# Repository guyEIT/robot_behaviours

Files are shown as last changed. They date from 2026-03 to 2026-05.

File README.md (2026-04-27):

# Robot Skills Framework — ROS 2 Jazzy

A discovery-based robot/instrument orchestration framework. Every skill — hardware-bound (MoveIt2 arm motion, pylabrobot instrument calls) or software-only (LLM-authored scripts) — is exposed as a self-advertising **ROS 2 action**. The orchestrator never hardcodes endpoints; it subscribes to latched `<node>/skills` manifests and dispatches goals over DDS.

Built on **ROS 2 Jazzy** + **MoveIt2** + a Python BehaviorTree.CPP-v4-compatible executor.

## Architecture

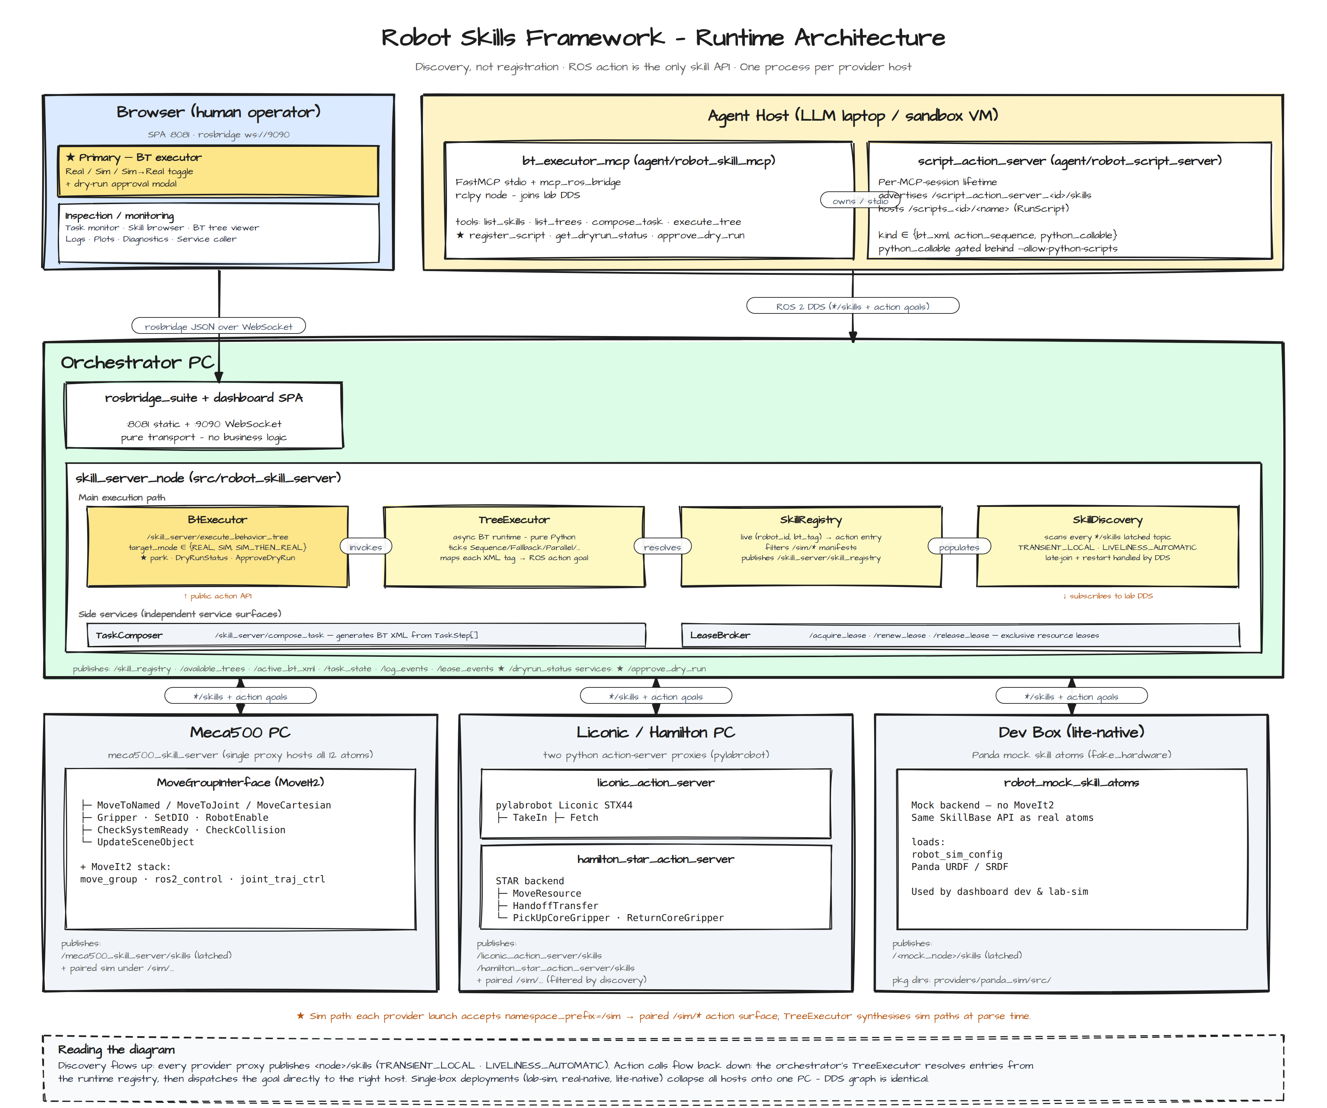
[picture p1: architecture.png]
Architecture diagram


Vector version: [architecture.svg](architecture.svg). Full text writeup: [architecture.md](architecture.md). Editable source: [architecture.excalidraw](architecture.excalidraw) (open at [excalidraw.com](https://excalidraw.com)).

**Core principles**

1. **A ROS action is the only skill API.** C++/MoveIt arm skills, Python/pylabrobot instrument skills, and agent-authored scripts all advertise the same way and are dispatched the same way.
2. **Discovery, not registration.** Every node hosting skills publishes a latched `<node>/skills` manifest with `TRANSIENT_LOCAL` durability and `LIVELINESS_AUTOMATIC` QoS. Restart and late-join are handled by DDS, not heartbeats.
3. **Topology = trust.** Code runs on the host that owns its execution context. The orchestrator never executes agent-authored code; it dispatches to ROS endpoints.
4. **One process per provider host.** Each robot/instrument PC runs a single skill-server-proxy node hosting all of that host's actions.
5. **Each top-level directory maps to one deployment role.**

## Directory layout

| Top-level dir | Role | Runs on |
|---|---|---|
| [lib/](lib/) | Shared libraries — host-agnostic, no runtime | Consumed by every host |
| [src/](src/) | Orchestrator processes + assets | Orchestrator PC |
| [agent/](agent/) | MCP-host processes + agent-local services | Agent's machine (anywhere on DDS) |
| [providers/](providers/) | Per-robot/instrument code | The robot/instrument PC |

### Providers

| Provider | Code | Skills |
|---|---|---|
| Mecademic Meca500 6-DoF arm | [providers/meca500/](providers/meca500/) | 12 MoveIt2 atoms (MoveToNamed/Joint/Cartesian, Gripper, SetDIO, RobotEnable, CheckSystemReady, CheckCollision, UpdateSceneObject, …) |
| Generic Panda 7-DoF (mock backend) | [providers/panda_sim/](providers/panda_sim/) | robot-agnostic mock skill atoms used by `lab-sim` and `lite-native`. The mocks no longer hardcode a robot — `lite-native` displays the Meca500 model in the dashboard while reusing the lightweight Python mocks; the panda URDF stays available for callers that override `joint_names` / `initial_positions` / `arm_joint_count` on the launch CLI. |
| PBI Liconic STX44 incubator | [providers/pbi_liconic/](providers/pbi_liconic/) | TakeIn, Fetch (pylabrobot) |
| Hamilton STAR liquid handler | [providers/pbi_liconic/](providers/pbi_liconic/) | MoveResource, HandoffTransfer, PickUpCoreGripper, ReturnCoreGripper |
| Imaging station (sim) | [providers/imaging_station/](providers/imaging_station/) | ImagePlate — currently a sim that writes placeholder PNGs; real driver swaps in via the same action |

Both Liconic and Hamilton are pulled from the `guyEIT/pbi_liconic` upstream as a `git subtree`. See [CLAUDE.md](CLAUDE.md) for the subtree pull/push commands.

The imaging-station provider is a fresh in-tree provider, not a subtree — it owns the `robot_skills_msgs/action/ImagePlate` interface and ships a sim backend so the campaign behaviour tree can run a full Liconic ↔ Hamilton ↔ Imager ↔ Hamilton ↔ Liconic loop without imager hardware. Real driver backends (BMG / Tecan / BioTek / microscope) plug into the same action interface.

## Quick start

### Prerequisites

- Pixi (Linux desktop). Docker Compose remains as a fallback path.
- A populated local conda channel at `~/channel` hosting `ros-jazzy-robot-skills-msgs` (one-time bootstrap).

### One-time bootstrap

```bash
bash scripts/bootstrap-msgs.sh
```

Builds `robot_skills_msgs` into `~/channel/`. Required because pixi 0.67 eagerly resolves all envs and the native envs reference `~/channel`.

### Run the whole lab in sim (single command)

```bash
pixi run lab-sim-up
# open http://localhost:8081 — pick test_meca500_sim / test_hamilton_sim / test_liconic_smoke
```

Brings up *every* provider sim + skill atoms + skill_server + dashboard in one `ros2 launch`. Validated end-to-end (hamilton 0.54 s, liconic 0.54 s, meca500 8.80 s).

### Per-provider sim (one provider in isolation)

```bash
pixi run meca500-sim-test    # MoveIt fake_hardware + Meca atoms + skill_server
pixi run hamilton-sim-test   # STAR sim backend + skill_server
pixi run liconic-sim-test    # Liconic sim backend + skill_server
```

Submit the matching test tree from [src/robot_behaviors/trees/](src/robot_behaviors/trees/).

### Single-box deployments

| Mode | Command | What runs |
|---|---|---|
| `lite-native` | `pixi run lite-native-up` | dashboard + orchestration with mock atoms (no MoveIt2) |
| `real-native` | `pixi run real-native-up` | full real-robot stack on one PC |
| `lab-sim` | `pixi run lab-sim-up` | every provider sim + dashboard |
| ★ `lab-up` | `pixi run lab-up` | `lab-sim` + paired `/sim/*` instances for `MODE_SIM_THEN_REAL` testing |

### Distributed production

Per-PC pixi envs install only what each box needs. All share `ros-jazzy-robot-skills-msgs` from `~/channel`.

| Env | Target PC | Tasks |
|---|---|---|
| `orchestrator` | control PC | `orchestrator-up` |
| `meca500-host` | Meca500 robot PC | `meca500-moveit-run` + `meca500-atoms-run`; `meca500-sim-up` for fake_hardware |
| `liconic-host` | Liconic / Hamilton PC | `liconic-up`, `liconic-sim-up`, `hamilton-up`, `hamilton-sim-up` |
| `lite-native` | dev box | `lite-native-up` |
| `real-native` | single-box real robot | `real-native-up` |

### Common workflows

```bash
# Rebuild only msgs after editing a .msg/.srv/.action
pixi run update-msgs

# Open a sourced ROS shell
pixi run lite-native-shell        # or real-native-shell, meca500-host shell, etc.

# Inspect the running ROS graph
pixi run status

# Run the test suite
pixi run test
```

## Calling skills

```bash
# List the skill registry (merged view of every */skills topic)
ros2 service call /skill_server/get_skill_descriptions \
  robot_skills_msgs/srv/GetSkillDescriptions \
  '{include_compounds: true, include_pddl: false}'

# Execute a behavior tree XML
ros2 action send_goal /skill_server/execute_behavior_tree \
  robot_skills_msgs/action/ExecuteBehaviorTree \
  "$(python3 -c 'import yaml,sys; xml=open(sys.argv[1]).read(); print(yaml.safe_dump({"tree_xml": xml, "tree_name": "demo", "target_mode": 0}, default_style="|"))' src/robot_behaviors/trees/move_to_home.xml)"

# Compose a tree from skill steps
ros2 service call /skill_server/compose_task \
  robot_skills_msgs/srv/ComposeTask \
  '{
    task_name: "my_task",
    sequential: true,
    steps: [
      {skill_name: "move_to_named_config", parameters_json: "{\"config_name\": \"home\"}"},
      {skill_name: "gripper_control",       parameters_json: "{\"command\": \"open\"}"}
    ]
  }'

# Sanity-check a plan against PDDL preconditions / effects before running it
ros2 service call /skill_server/validate_plan \
  robot_skills_msgs/srv/ValidatePlan \
  '{
    initial_state: ["robot_initialized", "gripper_open"],
    steps: [
      {skill_name: "move_to_named_config", parameters_json: "{\"config_name\": \"home\"}"},
      {skill_name: "pick_object",           parameters_json: "{}"}
    ]
  }'
# Returns valid=true + final_state, OR valid=false + first_failing_step
# + missing_preconditions[] pointing at the offending entry.
```

`target_mode` on `ExecuteBehaviorTree`: `0 = MODE_REAL` (default, back-compat), `1 = MODE_SIM` (one-shot dry-run), `2 = MODE_SIM_THEN_REAL` (sim → operator approval gate → real).

## Sim-before-real workflow ★

Long-running plans (multi-step assays, hours-long incubations) get a fast pre-flight against a paired `/sim/*` action surface, then a human approval gate before the real phase runs.

- Each provider launch accepts `namespace_prefix:=/sim` and wraps its action servers in a `PushRosNamespace` group.
- `SkillDiscovery` filters out `/sim/*` manifests so the registry is single-source-of-truth on real entries.
- `TreeExecutor` synthesises the sim path at parse time by string-prepending `/sim` — same XML, both phases.
- On a successful sim phase, `BtExecutor` latches a `DryRunStatus` on `/skill_server/dryrun_status` and waits on `/skill_server/approve_dry_run` (`ApproveDryRun.srv`). The dashboard surfaces an approve/reject modal.

## Long-lived campaign workflow ★

For trees that run for **weeks** — operators trickling plates in and out of the Liconic, cycling each through the Hamilton-iSWAP to the imaging station and back — the framework persists tree state to SQLite and resumes after a `skill_server` crash without losing progress.

**What survives a restart:**

- A SQLite-backed *persistent blackboard*: any key prefixed `persistent.` is mirrored to `~/.local/state/skill_server/tasks/{task_id}/state.db` (WAL mode). Type-checked at write — only JSON-serialisable values land on disk.
- *Per-node tick checkpoints* on every control / decorator / loop node (`Sequence` index, `Repeat` iteration, `RetryUntilSuccessful` attempt, `WaitUntil` deadline). On resume, the executor re-ticks from the root and each Checkpointable node hydrates its index — no work is repeated past the last successful child.
- *Action-inflight reconciliation*: every `RosActionNode` records `(node_path, server_name, goal_uuid, idempotent)` before submitting. If a goal was in flight at crash time, the resume path inspects the row — idempotent skills auto-resubmit; non-idempotent skills refuse and surface an alert for the operator to resolve via `OperatorDecision`.

**New control / utility nodes** in `tree_executor.py`:

- `KeepRunningUntilFailure`, `Repeat num_cycles="N"`, `WhileDoElse`
- `WaitUntil timestamp="{...}"` — wall-clock-aware sleep (deadline-preserving across restart)
- `BlackboardCondition key="..." expected="..."` — gate a subtree on a persistent flag
- `PopFromQueue` / `PushToQueue` — list-valued blackboard queues for operator-driven work
- `AdvancePlate` — post-cycle bookkeeping (increments cycle, recomputes `next_due_at`, retires when target reached)

**Operator services** — split between `bb_operator` (campaign-level state) and `skill_server` (framework-level execution control):

| Service | Owner | Purpose |
|---|---|---|
| `/bb_operator/add_plate` | sidecar | append a plate dict to `persistent.plate_queue` (trickle-in) |
| `/bb_operator/retire_plate` | sidecar | flag `plates.{name}.retiring = true` so the in-flight cycle finishes naturally and isn't re-queued |
| `/bb_operator/pause_campaign` | sidecar | toggle `persistent.paused`; `BlackboardCondition` gate halts the next iteration boundary |
| `/bb_operator/operator_decision` | sidecar | resolve a stuck non-idempotent action (`retry` / `skip-as-success` / `skip-as-failure` / `abort-tree`) |
| `/skill_server/pause_execution` | bt_executor | framework-level pause that sets `ctx.paused`, honoured at step boundaries by every control-flow node — works for any tree, not just campaigns |
| `/skill_server/cancel_active_task` | bt_executor | session-independent hard cancel; walks `_current_ctx`, sets `cancelled`, and tears down in-flight goals — reachable by *any* client (the action-cancel handshake requires the original goal id, which a restarted dashboard doesn't have) |

**Live dashboard view.** The dashboard's **Campaign** panel (added 2026-04-27) subscribes to `/skill_server/persistent_state` — a latched JSON snapshot of the active task's persistent blackboard, republished by `bb_operator` after every service handler + a 1 Hz timer. Renders the plate queue + per-name index as a table with cycle / cadence / next-due / status; surfaces **Add Plate** (modal dialog), **Pause after step** / **Resume**, **Cancel** (hard halt via `/skill_server/cancel_active_task`), and per-row **Retire** trash icons. The `Campaign` preset layout (Layouts → CAMPAIGN) tiles it alongside Task Monitor + BT Tree + Executor + Logs. Validated end-to-end via Playwright + chromium-headless: empty-state → submit campaign tree → AddPlate → Pause → Resume → Cancel.

**The campaign tree** lives at [src/robot_behaviors/trees/campaign/plate_imaging_campaign.xml](src/robot_behaviors/trees/campaign/plate_imaging_campaign.xml). Outer loop is `KeepRunningUntilFailure → BlackboardCondition(paused == false) → Sequence(Pop → WaitUntil → SubTree → AdvancePlate)`. Inner `PlateImageCycle` subtree wraps the iSWAP transfers, ImagePlate, and Liconic round-trip in a `RetryUntilSuccessful num_attempts=2`.

**Skill idempotency** is declared per atom in `SkillDescription.idempotent` (defaults to `false`). The resume path uses it to decide whether to auto-resubmit on goal-gone or to halt and ask the operator.

## MCP / agent surface

Agents (LLMs, MCP clients) drive the lab through [agent/robot_skill_mcp/](agent/robot_skill_mcp/) — a FastMCP stdio server bridged into ROS:

| Tool | Purpose |
|---|---|
| `list_skills`, `list_trees` | introspect the runtime registry |
| `compose_task` | build a BT XML from steps |
| `execute_tree` | dispatch `/skill_server/execute_behavior_tree` |
| `register_script`, `list_scripts`, `delete_script` | session-scoped agent-authored skills |
| `get_dryrun_status`, `approve_dry_run` | drive the sim-then-real gate |

Agent-authored scripts run on the agent's host via [agent/robot_script_server/](agent/robot_script_server/) — the orchestrator never executes agent code; from its point of view a registered script is just another `RunScript`-typed action.

## Live update

`./src` is bind-mounted into the dev container; `colcon build --symlink-install` symlinks Python and XML share files back to source.

| Change type | Action |
|---|---|
| Behavior tree XML | save the file — `BtExecutor` polls every 2 s, dashboard updates over the latched topic |
| Python orchestrator code | save the file — symlinked. Restart the node only if it caches state at startup |
| C++ atoms | `colcon build --packages-select <pkg>` + node restart |
| Frontend | `vite build` + `colcon build --symlink-install --packages-select robot_dashboard` (or `pixi run dashboard-dev` for hot reload) |

## Adding a skill

See [docs/adding-skills.md](docs/adding-skills.md) and the Claude Code commands:

- `/new-skill-atom` — generic primitive (lib/robot_arm_skills) or provider-specific atom
- `/new-compound-skill` — vetted, persisted compound skill
- `/new-behavior-tree` — XML tree
- `/debug-skill` — diagnose a failing skill or tree

## Docker fallback

Local Pixi is the preferred path; Docker remains as a fallback.

```bash
pixi run lite-up   pixi run lite-logs    pixi run lite-down
pixi run real-up   pixi run real-logs    pixi run real-down
pixi run docker-status
```

| Container | Image | Purpose |
|---|---|---|
| `ros2_robot_skills_lite` | `ros2-jazzy-robot-skills-lite` | lite mock skill stack |
| `ros2_robot_skills_dev` | `ros2-jazzy-robot-skills` | real robot skill server |

Containers use host networking for DDS discovery and bind-mount `./src`.

## Further reading

- [architecture.md](architecture.md) — full architecture writeup
- [CLAUDE.md](CLAUDE.md) — development environment, validation status, known follow-ups
- [docs/adding-skills.md](docs/adding-skills.md)

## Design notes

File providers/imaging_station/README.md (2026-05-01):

# imaging_station provider

Generic plate imaging-station provider for the Robot Skills Framework. Owns
the `robot_skills_msgs/action/ImagePlate` action; ships a sim backend that
writes placeholder PNGs and a live NDI receiver node that republishes a
remote NDI source (e.g. ZowieBox-40435) as `sensor_msgs/Image`.

## Packages

- **`imaging_station`** (ament_python) — the action server + bridge node.
  - `imaging_station_sim_node` — placeholder PNG sim, serves `ImagePlate`.
  - `imaging_station_ndi_node` — spawns the C++ NDI bridge, publishes frames.
- **`imaging_station_ndi_bridge`** (ament_cmake) — the native `ndi_av_bridge`
  binary. Vendored verbatim from the experiment_collector workspace.

## Sim backend

```
ros2 launch imaging_station imaging_station_sim.launch.py
```

Writes one PNG per requested site under
`~/.local/state/imaging_station/{plate_name}/{epoch_ms}_{counter}/site_{i}.png`.
No hardware required.

## NDI bridge node (live ZowieBox / any NDI source)

Connects to a named NDI source and publishes BGR8 `sensor_msgs/Image` frames
on `/imaging_station/image_raw`.

```
ros2 launch imaging_station imaging_station_ndi.launch.py \
  ndi_source_name:="ZOWIEBOX-40435 (ZowieBox-40435)"
ros2 run rqt_image_view rqt_image_view /imaging_station/image_raw
```

### Prerequisites — NDI 6 SDK

The bridge `dlopen`s `libndi.so.6` at runtime; the build needs
`Processing.NDI.Lib.h` at compile time. Neither is on conda-forge (NDI is
license-gated by Vizrt), so you must install it once per pixi env:

1. Download `Install_NDI_SDK_v6_Linux.tar.gz` from
   <https://ndi.video/for-developers/ndi-sdk/download/>.
2. Drop it at `vendor/ndi/Install_NDI_SDK_v6_Linux.tar.gz`.
3. Run `pixi run setup-ndi` (or `bash scripts/setup-ndi-host.sh` directly —
   the script does not require an active pixi env).
4. Run `pixi run lite-native-install` so the bridge package picks up the
   newly-installed headers and produces the `ndi_av_bridge` binary.

The script ([scripts/setup-ndi-host.sh](../../scripts/setup-ndi-host.sh))
extracts the tarball, runs the Vizrt installer non-interactively, and copies
headers + `libndi.so.6` into `$HOME/.ndi-sdk/{include,lib}/`. That host-stable
per-user prefix is reachable both by the pixi-build-ros build sandbox (via
`FindNDISdk.cmake`) and by the runtime (the bridge dlopens `libndi.so.6`
through `IMAGING_STATION_NDI_RUNTIME_DIR`, which the `lite-native` activation
env points at the same dir).

If you skip step 3, `pixi install -e lite-native` still succeeds — the bridge
build prints a `STATUS` warning and the package installs without the
executable, so unrelated lite-native development isn't blocked.

### Discovery on multi-NIC hosts

libndi's built-in mDNS implementation can silently fail on hosts with multiple
network interfaces (Linux multicast picks one route, which may not be the one
the source advertises on). The node falls back to `avahi-browse` automatically
to resolve `host:port`, then passes that to the bridge as `--url-address` so
the bridge connects directly without going through libndi's mDNS at all.

If discovery still fails, force it with the `url_address` parameter:

```
ros2 launch imaging_station imaging_station_ndi.launch.py \
  url_address:=10.6.105.98:5961
```

### "Video decoder not found"

NDI 6.3.x dlopens `libavcodec.so.61` / `libavutil.so.59` (FFmpeg 7.x SONAMEs)
and a cluster of codec helpers (`dav1d`, `openjp2`, `speex`, `lcms2`, `libva`).
Ubuntu's system FFmpeg is too old (60/58); conda-forge has the right versions
but only when explicitly pulled in.

The fix is wired through pixi: `[feature.lite-native.dependencies]` declares
`gst-libav` (transitively pulls FFmpeg 7.x), plus `lcms2 / dav1d / openjpeg /
speex / avahi`. `pixi run setup-ndi` then assembles
`$PROJECT_ROOT/.ndi-runtime-bundle/lib/` by copying `libndi.so.6` from
`$HOME/.ndi-sdk/` and the FFmpeg + codec libs from `$CONDA_PREFIX/lib`,
creating the SONAME aliases NDI looks for (`libavcodec-ndi.so.61` →
`libavcodec.so.61.X.Y.Z` etc.). The bundle path is exported as
`IMAGING_STATION_NDI_RUNTIME_DIR` by the `lite-native` activation env.

If you bump conda-forge versions later (e.g. FFmpeg 8.x lands), rebuild the
bundle to refresh the symlinks:

```
pixi run setup-ndi-bundle
```

### Network

NDI uses mDNS for source discovery; the imager and the host running the node
must be on the same broadcast domain (or use NDI Discovery Server / explicit
`url_address` overrides). Confirm your ZowieBox is visible:

```
ros2 run imaging_station_ndi_bridge ndi_av_bridge --help    # bridge CLI
```

…and look for the source name in `imaging_station_ndi_node`'s startup log
("Visible NDI sources (N): [...]").

### Parameters

| name | default | meaning |
|---|---|---|
| `ndi_source_name` | `"ZOWIEBOX-40435 (ZowieBox-40435)"` | NDI source to subscribe to |
| `frame_id` | `imaging_station_camera_optical_frame` | `frame_id` stamped on every Image |
| `target_fps` | `0.0` | Cap publish rate (0 = pass through) |
| `discovery_timeout_sec` | `5.0` | mDNS discovery wait at startup |
| `bandwidth` | `highest` | NDI receiver bandwidth (`highest`/`lowest`)  |
| `image_topic` | `image_raw` | Topic name (under `/imaging_station/`) |
| `camera_info_topic` | `camera_info` | CameraInfo topic name (under `/imaging_station/`) |
| `camera_info_url` | `<share>/imaging_station/calibration/zowiebox_camera_info.yaml` | Calibration YAML; empty/missing → 50° HFOV placeholder |
| `startup_timeout_sec` | `12.0` | Bridge waits this long for the source |

The node publishes a `sensor_msgs/CameraInfo` paired 1:1 with each Image
(matching `header.stamp` + `frame_id`, both `BEST_EFFORT` QoS). When
`camera_info_url` points at a present file the standard
`camera_calibration_parsers` YAML is loaded; otherwise the node
synthesises a 50° HFOV pinhole `CameraInfo` from the live frame
dimensions — good for RViz frustum visualisation, **not** for metric
reconstruction. Replace
[calibration/zowiebox_camera_info.yaml](src/imaging_station/calibration/zowiebox_camera_info.yaml)
with real `camera_calibration` output once a checkerboard pass has been
done at the macro lens's nominal working distance.

The static TF `microscope_camera → imaging_station_camera_optical_frame`
(0.193 m along +Z, 180° roll so Z-forward points down through the lens —
ROS optical-frame convention X-right Y-down Z-forward; override
translation with `optical_offset_z:=…` and rotation with
`optical_roll:=…` / `optical_pitch:=…` / `optical_yaw:=…`) is
published by
[imaging_station_scene.launch.py](launch/imaging_station_scene.launch.py),
which `meca500_bringup/moveit.launch.py` already includes via
`show_imaging_station:=true`. Run `pixi run meca500-real-up` (or the sim
equivalent) and the optical frame appears in RViz relative to
`meca_base_link` without the bridge running.

## Follow-ups

- A real `ImagePlate` backend that captures N frames per site from the live
  NDI stream and writes them to `output_root` (replacing or living alongside
  `sim_backend`). Today the sim and the NDI bridge run independently.
- Audio packets from the bridge are dropped in v1; add a ROS publisher when
  a consumer materialises.
- Replace the placeholder
  [zowiebox_camera_info.yaml](src/imaging_station/calibration/zowiebox_camera_info.yaml)
  with real intrinsics from `camera_calibration` once the macro lens has
  been calibrated against a checkerboard at its nominal working distance.

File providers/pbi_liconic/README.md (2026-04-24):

# plr — pylabrobot + ROS 2 for a Hamilton STAR

Scripts and a ROS 2 action server for driving a Hamilton STAR (8-channel)
through [pylabrobot](https://github.com/PyLabRobot/pylabrobot), including
off-deck plate handoffs to external instruments (incubator, cytomat, etc.)
via the STAR's firmware "hotel" commands.

Everything runs inside [`pixi`](https://pixi.sh) environments so the
underlying conda + ROS 2 Humble (RoboStack) stack stays reproducible.

## Quick start

```bash
pixi install -e ros2             # builds the three ROS 2 packages as
                                 # conda packages via pixi-build-ros

# One shell — run the action server against real hardware
pixi run -e ros2 action-server

# Another shell — drive it
pixi run -e ros2 ros2-move-to-incubator -- --yes
```

To run without hardware (STAR chatterbox simulator):

```bash
pixi run -e ros2 action-server-sim
```

Editing a source file? Just rerun `pixi run -e ros2 <task>` — pixi-build
sees the change and rebuilds the affected package automatically. No
`colcon build`, no `source install/setup.bash`.

## Repo layout

```
scripts/       Direct-hardware scripts + ROS 2 client scripts + the
               teach pendant. Each one is runnable via a pixi task.
ros2_ws/       The ROS 2 workspace. Five packages:
  hamilton_star_msgs/    STAR action/msg/srv definitions
  hamilton_star_ros/     STAR action server implementation
  hamilton_star_bringup/ STAR launch files + default deck + handoff config
  liconic_msgs/          STX incubator action/msg/srv definitions
  liconic_ros/           STX action server + launch file + plate registry
```

## Two worlds

The repo has two sets of tools depending on how much infrastructure you
want in the way:

- **Direct scripts** (`scripts/`, default pixi env) — open their own USB
  connection to the STAR, do one thing, disconnect. Useful for bring-up,
  recovery, and teaching calibrations. Examples: `pixi run test-iswap`,
  `pixi run iswap-teach`, `pixi run iswap-release`.
- **ROS 2 action server** (`ros2_ws/`, `ros2` pixi env) — persistent
  process, one USB connection, async actions + services. This is what
  bigger workflows should target. Launched via
  `pixi run -e ros2 action-server`; client scripts in `scripts/` with a
  `test_ros2_*.py` prefix hit it via ROS 2 actions.

## ROS 2 architecture

```
hamilton_star_msgs/     action + msg + srv definitions
hamilton_star_ros/      the node implementation
  action_server.py      rclpy plumbing (one action per goal type)
  machine.py            async facade over pylabrobot.LiquidHandler
  machine_fsm.py        operational state + substate gating
  machine_lock.py       per-channel / per-resource RW lock
  iswap_handoff.py      6-stage manual-jog recipe for off-deck transfers
  handoff_registry.py   runtime CRUD for off-deck handoff sites
  asyncio_bridge.py     bridges rclpy's callback threads to one asyncio loop
hamilton_star_bringup/  launch files + deck/handoff config
```

### Actions & services

The server exposes roughly two flavours:

- **Pipetting / move**: `pick_up_tips`, `drop_tips`, `aspirate`, `dispense`,
  `transfer`, `aspirate96` etc., `move_resource`, `pick_up_core_gripper`,
  `return_core_gripper`, `jog_channel`.
- **iSWAP-specific**: `handoff_transfer` (6-stage manual-jog, diagnostic
  per-stage feedback — useful when the firmware atomic paths misbehave).

Plus services for lifecycle and configuration: `reset_error`,
`abort_motion`, `initialize_module`, `load_deck`, `serialize_deck`,
`list_resources`, `get_status`, `acknowledge_plate_released`,
`define_handoff`, `list_handoffs`, `delete_handoff`.

### Off-deck plate handoffs: the one-line story

```python
await move_resource(resource="six_well_01", to="incubator_handoff")
```

The server has a **handoff registry** (`handoff_registry.py`) of off-deck
sites — each entry holds the XYZ coordinate, the iSWAP grip parameters,
and the firmware hotel approach parameters (`hotel_depth`,
`hotel_clearance_height`). When you register a handoff via
`~/define_handoff`, the server also injects a matching `ResourceHolder`
onto the deck tree at that coordinate, so `MoveResource.to = <name>`
Just Works — you don't have to think about "is this on-deck or off-deck".
The server auto-detects that `to` names a registered handoff and routes
through pylabrobot's firmware-atomic `use_unsafe_hotel=True` path.

For tuning or diagnostic flows where you want step-by-step visibility,
`handoff_transfer` (6-stage manual jog) is still available.

### State machine

`machine_fsm.py` is the single authority over `op_state` (Disconnected /
Initializing / Idle / BusyShared / BusyExclusive / Aborting / Error) and
a bundle of orthogonal substate flags: per-channel tip/gripper state,
iSWAP init / y-path / holding-plate / drive-faulted / at-safe-pose, and
the last reached handoff stage (for post-mortem). Key recovery semantics:

- Any firmware exception during an iSWAP-driven action sets
  `iswap_drive_faulted = True`. Future goals that need the iSWAP are
  rejected at the FSM gate until cleared.
- `~/reset_error` does **soft** firmware recovery: re-init the iSWAP,
  verify it responds with a position query, *then* clear the FSM. If the
  firmware is still faulted, the service returns `success=False` with a
  hint to restart the server or power-cycle the STAR.
- `iswap_holding_plate` survives exceptions on purpose — the operator
  must physically inspect the gripper (optionally run `iswap-release`)
  and acknowledge via `~/acknowledge_plate_released`.

The [FSM self-healing plan](.claude/plans/what-can-we-do-prancy-river.md)
in the repo walks through the design.

## Pixi tasks

### Default env (direct, no ROS)

| Task | What it does |
|---|---|
| `pixi run test-star` | Minimal hardware ping |
| `pixi run test-sim` | Same against the chatterbox sim |
| `pixi run test-gripper` | CoRe II gripper pickup/return |
| `pixi run test-iswap` | iSWAP sanity test |
| `pixi run iswap-teach` | Launch the FastAPI teach pendant (port 8080) |
| `pixi run test-iswap-grab` | Pick up a 6-well plate (direct) |
| `pixi run iswap-release` | Recovery: release a stuck plate and park |
| `pixi run iswap-to-incubator` | Direct manual-jog transfer to the incubator |
| `pixi run iswap-from-incubator` | Same, reverse direction |

### `ros2` env (action server + clients)

| Task | What it does |
|---|---|
| `pixi install -e ros2` | Build & install the three ROS 2 packages as conda packages (pixi-build-ros). Re-runs automatically when source changes. |
| `pixi run -e ros2 action-server` | Launch the action server vs real hardware |
| `pixi run -e ros2 action-server-sim` | Same, against the chatterbox simulator |
| `pixi run -e ros2 test-ros2-sim` | `pytest` the hamilton_star_ros tests |
| `pixi run -e ros2 ros2-iswap-to-incubator` | HandoffTransfer (6-stage) client |
| `pixi run -e ros2 ros2-iswap-from-incubator` | HandoffTransfer, reverse |
| `pixi run -e ros2 ros2-move-to-incubator` | **Canonical** MoveResource-to-registered-handoff |
| `pixi run -e ros2 liconic-server` | Launch the Liconic STX action server (own process, own /dev/liconic_stx44, plate-registry JSON at `~/.local/state/liconic/plate_registry.json`) |
| `pixi run -e ros2 liconic-roundtrip` | Client: Liconic take-in + fetch (needs only the Liconic server running) |
| `pixi run -e ros2 liconic-workcell-roundtrip` | Client: full Hamilton → Liconic → Hamilton round-trip (needs BOTH action servers running) |

Pass extra args to any ROS 2 client with `--`:

```bash
pixi run -e ros2 ros2-move-to-incubator -- --yes --rails 15
```

## Handoff registry by example

```bash
# Look at what's already registered (seeded from handoffs.yaml on boot)
ros2 service call /hamilton_star_action_server/list_handoffs \
    hamilton_star_msgs/srv/ListHandoffs '{}'

# Register a new off-deck site
ros2 service call /hamilton_star_action_server/define_handoff \
    hamilton_star_msgs/srv/DefineHandoff '{
      handoff: {
        name: "cytomat",
        x: -216.0, y: 350.0, z: 120.0,
        plate_width: 80.0,
        rotation: "LEFT", wrist: "STRAIGHT", grip_direction: "FRONT",
        hotel_depth: 500.0,
        hotel_clearance_height: 8.0,
      },
      replace_existing: true
    }'

# Now move a plate there via the generic MoveResource action
ros2 action send_goal /hamilton_star_action_server/move_resource \
    hamilton_star_msgs/action/MoveResource \
    '{ resource: "six_well_01", to: "cytomat", transport: "iswap" }'
```

## Development

```bash
pixi run -e ros2 test-ros2-sim    # full sim-backed pytest
rm -rf .pixi/build && pixi install -e ros2   # force a clean rebuild
```

Pure-Python unit tests (FSM, locks, bridge, registry) don't need rclpy
and run in `~1 second`; the rclpy-backed tests spin up an in-process
action server with the chatterbox simulator.

### ROS 2 build

The three packages under `ros2_ws/src/` are built by
[pixi-build-ros](https://pixi.prefix.dev/latest/build/backends/pixi-build-ros/)
(preview feature in pixi). Each package has its own `pixi.toml`
declaring the backend, the ROS distro (`humble`), and any sibling
path-deps; the root `pixi.toml` references them via conda-style path
entries under `[feature.ros2.dependencies]`. Pixi resolves, builds,
and installs the packages into the `ros2` env as real conda packages,
so `import hamilton_star_msgs.action`, `ros2 launch hamilton_star_bringup
…`, and the pytest suite all work without a `source install/setup.bash`
step.

The legacy `ros2_ws/build/`, `ros2_ws/install/`, `ros2_ws/log/` dirs
from the old colcon setup can be deleted — they're not used.

## Hardware setup

Plug in the STAR's USB cable; install the udev rule once:

```bash
sudo ./install-udev.sh
```

See [README-hamilton-udev.md](README-hamilton-udev.md) for details.

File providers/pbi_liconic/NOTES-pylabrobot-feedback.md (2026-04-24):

# pylabrobot — iSWAP off-deck handoff, questions

We're trying to drive a plate from an on-deck carrier (rails=20) to an
off-deck incubator dock at X ≈ -219 mm on a Hamilton STAR via the atomic
path (`lh.move_resource(..., use_unsafe_hotel=True)`). The 6-stage manual
jog recipe works; the atomic one doesn't, and we suspect we're holding
something the wrong way round. Four questions where your guidance would
help.

---

## 1. Is there a way to address the iSWAP shoulder and wrist independently in the atomics?

Our teach-pendant calibration for the incubator dock is
`shoulder=LEFT, wrist=STRAIGHT`. We can reproduce it through the manual
helpers (`rotate_iswap_rotation_drive` + `rotate_iswap_wrist`) but we
can't find a way to express it through `GripDirection`:

- `GripDirection.LEFT` — plate ends up rotated 180° in the gripper
  (looks like shoulder LEFT but the wrist is offset from STRAIGHT).
- `GripDirection.RIGHT` — plate orientation correct, but the arm now
  extends the wrong way and can't reach a left-side dock.

None of the four `GripDirection` values produce the
`shoulder=LEFT, wrist=STRAIGHT` combo we need.

Is there an existing way to pass the two drives separately to the
atomics (`iswap_get_plate`, `unsafe.put_in_hotel`), or is the manual-jog
path the expected route for calibrations like this?

---

## 2. Is `use_unsafe_hotel` meant to be set per-side?

For an on-deck → off-deck transfer, only the drop side should run the
hotel firmware command — calling `get_from_hotel` (PO) on the on-deck
plate hits `R027 PositionNotReachable`. `LiquidHandler.move_resource`
forwards `**backend_kwargs` to both `pick_up_resource` and
`drop_resource`, so `use_unsafe_hotel=True` goes to both.

Is there a supported way to split kwargs per side that we've missed?
We've worked around it by calling `pick_up_resource` and `drop_resource`
separately, but it felt like going around the one-call `move_resource`
API.

---

## 3. What happens if `pickup_direction` differs from `drop_direction` on the atomic path?

If we pick up with `GripDirection.FRONT` and then
`put_in_hotel(grip_direction=LEFT)`, the firmware atomic fails with
`R027`. The PO/PI commands don't seem to rotate the wrist to match
`gr` during the approach; they plan as if the arm is already oriented.

Is there a layer we should be going through that inserts a wrist
rotation between pickup and drop when the directions differ, or is
matching them a hard caller requirement?

---

## 4. Post-init pose + first rotation crashes the wrist

After `initialize_iswap` (FI) the arm sits at Y ≈ 626 mm. Any atomic
that needs a shoulder rotation from that pose binds the wrist against
the back wall:

```
R002/82: Wrist twist drive movement error: drive locked or incremental sensor fault
```

`park_iswap` (PG) doesn't help — it also moves Y far back. We pre-park
manually with `move_iswap_y(330)` before any iSWAP atomic, which works,
but it feels like we're papering over something the atomic should
handle itself. Is manual pre-parking the intended pattern, or is there
a helper that does the right thing?

---

Happy to send diffs, teach files, or firmware traces for any of the
above if useful. The manual-jog path is fine as a fallback, but we'd
like to get `move_resource` working for handoffs where we can.

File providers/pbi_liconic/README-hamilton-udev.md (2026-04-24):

# Hamilton STAR USB setup

The STAR appears on USB as vendor `08af` (Hamilton Bonaduz AG). To let this
project talk to it without running as root, and to give the device a stable
name, install the included udev rule:

```bash
./install-udev.sh
```

What it does:

1. Copies [99-hamilton.rules](99-hamilton.rules) to
   `/etc/udev/rules.d/99-hamilton.rules`.
2. Reloads udev and re-triggers device events.
3. Adds your user to the `plugdev` group if it isn't already.

After running it:

- **Log out and back in** so the new group membership takes effect.
- **Replug the STAR's USB cable** (or power-cycle the robot) so the rule
  applies to the live device node.

## Verification

- `ls -l /dev/hamilton_star` — should be a symlink owned by group `plugdev`.
- `pixi run lsusb` — should list an `08af:` device.
- `pixi run test-star` — connects, prints machine configuration, exits.

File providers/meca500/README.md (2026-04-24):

# meca500_ros2
ROS 2 Controllers for the Mecademic Meca500 robot.

# Requirements
* [pixi](https://pixi.sh)
* ROS 2 Jazzy (provisioned automatically by pixi via RoboStack — no system install required)

# Installation
```bash
git clone git@github.com:guyEIT/meca500_ros2.git
cd meca500_ros2
pixi install
```

`pixi install` resolves every `package.xml` dependency against RoboStack and builds the four ROS packages via [pixi-build-ros](https://prefix-dev.github.io/pixi-build-backends/backends/pixi-build-ros/).

# Run Controller

```bash
pixi run launch-moveit
```

Other tasks (`pixi task list` for the full set):

* `pixi run launch-calibration` — startup calibration launch
* `pixi run moveit-setup` — MoveIt setup assistant
* `pixi run rviz` — rviz2
* `pixi run -e tools optimize-mecatable --help` — mesh optimizer (isolated env, no ROS deps)

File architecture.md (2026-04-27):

# Robot Skills Framework — Architecture

A ROS 2 Jazzy workspace that exposes every robot/instrument skill — hardware-bound or software-only — as a self-advertising ROS action. The orchestrator discovers skills at runtime by subscribing to latched `*/skills` topics; nothing is hardcoded. Behavior trees are authored as XML, composed from skill steps, and executed by a Python tree executor.

## Core principles

1. **A ROS action is the only skill API.** C++/MoveIt arm skills, Python/pylabrobot instrument skills, and agent-authored scripts all advertise the same way and are dispatched the same way.
2. **Discovery, not registration.** Every node hosting skills publishes a latched `<node>/skills` manifest with `TRANSIENT_LOCAL` durability and `LIVELINESS_AUTOMATIC` QoS. Restart and late-join are handled by DDS, not heartbeats.
3. **Topology = trust.** Code runs on the host that owns its execution context. The orchestrator never executes agent-authored code; it dispatches to ROS endpoints. An LLM-authored script lives on the agent's machine — DDS sees it as just another action server.
4. **One process per provider host.** Each robot/instrument PC runs a single skill-server-proxy node hosting all of that host's actions, not a fleet of one-skill-per-node executables.
5. **Each top-level directory maps to one deployment role.** A package's location tells you where it runs.

## Runtime graph

```
  EXTERNAL CLIENTS — neither lives on the orchestrator.

  ┌─────────────────────────────────────┐    ┌────────────────────────────────────────────────────┐
  │ Browser (human)                     │    │ AGENT HOST (LLM laptop / sandbox VM)               │
  │   loads SPA from :8081              │    │  ┌──────────────────────────────────────────────┐  │
  │   live ROS via ws://9090            │    │  │ Agent / LLM (Claude Code, custom MCP client) │  │
  │   (rosbridge)                       │    │  │   spawns bt_executor_mcp as stdio subprocess │  │
  │                                     │    │  └──────────────────┬───────────────────────────┘  │
  │   Surfaces: BT executor (with       │    │                     │ stdio                         │
  │     Real / Sim / Sim→Real toggle    │    │                     ▼                               │
  │     + dry-run approval modal),      │    │  ┌──────────────────────────────────────────────┐  │
  │     task monitor, skill browser,    │    │  │ bt_executor_mcp   (agent/robot_skill_mcp)    │  │
  │     BT tree viewer, logs, plots,    │    │  │   FastMCP stdio + mcp_ros_bridge             │  │
  │     diagnostics                     │    │  │   rclpy node — joins lab DDS                 │  │
  └────────────┬────────────────────────┘    │  │   tools: list_skills / list_trees /          │  │
               │ rosbridge JSON                │  │          compose_task / execute_tree /       │  │
               │ over WebSocket                │  │        ★ register_script /                   │  │
               │ ws://orchestrator:9090        │  │        ★ get_dryrun_status /                 │  │
               │                               │  │        ★ approve_dry_run                     │  │
               │                               │  └────────────────────┬─────────────────────────┘  │
               │                               │                       │ owns                       │
               │                               │                       ▼                            │
               │                               │  ┌──────────────────────────────────────────────┐  │
               │                               │  │ script_action_server                         │  │
               │                               │  │   (agent/robot_script_server)                │  │
               │                               │  │   per-MCP-session lifetime                   │  │
               │                               │  │   advertises /script_action_server_<id>/skills│ │
               │                               │  │   hosts /scripts_<id>/<name> (RunScript)     │  │
               │                               │  └──────────────────────────────────────────────┘  │
               │                               └─────────────────────┬──────────────────────────────┘
               │                                                     │ */skills (latched) +
               │                                                     │ action goal calls
               │                                                     │ over ROS 2 DDS
┌──────────────┼─────────────────────────────────────────────────────┼─────────────────────────────┐
│ ORCHESTRATOR │                                                     ▼                             │
│   PC         ▼                                                                                   │
│  ┌────────────────────────────────────┐                                                          │
│  │ rosbridge_suite + dashboard SPA    │                                                          │
│  │   :8081 static + :9090 WebSocket   │                                                          │
│  │   pure transport, no business logic│                                                          │
│  └─────────────────┬──────────────────┘                                                          │
│                    │ ROS 2 service / action / topic                                              │
│                    ▼                                                                             │
│  ┌─────────────────────────────────────────────────────────────────────────────────────────────┐ │
│  │ skill_server_node                          (src/robot_skill_server)                         │ │
│  │   • SkillDiscovery — subscribes to every */skills topic; ignores /sim/*                     │ │
│  │   • TreeExecutor    — async BT runtime; resolves (robot_id, bt_tag) → action server         │ │
│  │                       prepends /sim to server_name when target_mode = SIM                   │ │
│  │   • BtExecutor      — /skill_server/execute_behavior_tree (ExecuteBehaviorTree.action,      │ │
│  │                       target_mode ∈ {REAL, SIM, SIM_THEN_REAL}, optional sim_tree_xml)      │ │
│  │                     ★ Sim_then_Real: park, publish DryRunStatus, wait on ApproveDryRun      │ │
│  │   • TaskComposer    — generates BT XML from TaskStep lists                                  │ │
│  │   • LeaseBroker     — exclusive resource leases (TTL, renewal)                              │ │
│  │   • SkillRegistry   — vetted shared compound skills (persistent on disk)                    │ │
│  │   publishes:  /skill_server/skill_registry  /available_trees  /active_bt_xml                │ │
│  │              /task_state  /log_events  /lease_events                                        │ │
│  │            ★ /skill_server/dryrun_status (latched DryRunStatus)                             │ │
│  │   services:                                                                                 │ │
│  │            ★ /skill_server/approve_dry_run (ApproveDryRun)                                  │ │
│  └─────────────────────────────────────────────────────────────────────────────────────────────┘ │
└────────────────────┬───────────────────────────┬───────────────────────────────┬─────────────────┘
                     │                           │                               │
                     │ */skills (latched, TRANSIENT_LOCAL, LIVELINESS_AUTOMATIC) │
                     │ + action goal calls (real path: bare; sim path: /sim/...) │
                     │                           │                               │
   ┌─────────────────┴─────┐  ┌─────────────────┴────────────┐  ┌────────────────┴───────────┐
   │ MECA500 PC            │  │ LICONIC PC                   │  │ DEV BOX (lite-native)      │
   │  meca500_skill_server │  │  liconic_action_server       │  │  panda mock skill atoms    │
   │   ┌─────────────────┐ │  │  ┌─────────────────────────┐ │  │  (mock backend, fake_hw)   │
   │   │MoveGroupInterface│ │  │  │pylabrobot Liconic STX44│ │  │                            │
   │   │ ├─ MoveToNamed* │ │  │  │  ├─ TakeIn / Fetch     │ │  │  loads:                    │
   │   │ ├─ MoveToJoint* │ │  │  └─────────────────────────┘ │  │   robot_sim_config         │
   │   │ ├─ MoveCartesian│ │  │  hamilton_star_action_server │  │   (Panda URDF/SRDF)        │
   │   │ ├─ Gripper /    │ │  │  ┌─────────────────────────┐ │  │                            │
   │   │ │   SetDIO /    │ │  │  │STAR backend            │ │  │  publishes:                │
   │   │ │   RobotEnable │ │  │  │  ├─ MoveResource       │ │  │   <node>/skills            │
   │   │ ├─ CheckSystem* │ │  │  │  ├─ HandoffTransfer    │ │  │                            │
   │   │ ├─ CheckCollis* │ │  │  │  └─ PickUp/ReturnCore* │ │  │  pkg dirs:                 │
   │   │ └─ UpdateScene* │ │  │  └─────────────────────────┘ │  │   providers/panda_sim/src/ │
   │   └─────────────────┘ │  │                              │  │                            │
   │  publishes:           │  │  publishes:                  │  │                            │
   │   /meca500_skill_     │  │   /liconic_action_server/    │  │                            │
   │     server/skills     │  │     skills                   │  │                            │
   │   + paired sim under  │  │   /hamilton_star_action_     │  │                            │
   │     /sim/...          │  │     server/skills            │  │                            │
   │  + MoveIt2 stack      │  │   + paired sim under         │  │                            │
   │   (move_group,        │  │     /sim/... (filtered by    │  │                            │
   │    ros2_control,      │  │      discovery)              │  │                            │
   │    joint_traj_ctrl)   │  │                              │  │                            │
   │                       │  │  pkg dirs:                   │  │                            │
   │  pkg dirs:            │  │   providers/pbi_liconic/     │  │                            │
   │   providers/meca500/  │  │     ros2_ws/src/{liconic_ros,│  │                            │
   │     src/meca500_*     │  │     hamilton_star_ros, …}    │  │                            │
   └───────────────────────┘  └──────────────────────────────┘  └────────────────────────────┘
```

**Reading the diagram.** Two external client paths — browser and agent — neither runs on the orchestrator. Discovery flows up (every proxy publishes `<node>/skills`); action calls flow back down (the orchestrator's `TreeExecutor` resolves entries from the runtime registry, then dispatches the goal directly to the right host). Single-box deployments (`lab-sim`, `real-native`, `lite-native`) collapse all hosts onto one PC; the DDS graph is identical, the network just stops being involved.

**Sim-before-real (★).** Each provider launch accepts `namespace_prefix:=/sim` and wraps its action servers in a `PushRosNamespace` group, producing a paired `/sim/<provider>/...` action surface. Discovery filters `/sim/*` manifests so the registry stays single-source-of-truth on real paths; the executor synthesises sim paths at parse time by string-prepending `/sim`. The `lab-up` topology brings up real and sim side-by-side on one box for the dry-run-then-real workflow.

**Additional provider not shown above:** `imaging_station` ([providers/imaging_station/](providers/imaging_station/)) advertises `ImagePlate` (idempotent) at `/imaging_station_sim/image_plate`. The campaign tree ([src/robot_behaviors/trees/campaign/plate_imaging_campaign.xml](src/robot_behaviors/trees/campaign/plate_imaging_campaign.xml)) drives plates Liconic → Hamilton iSWAP → imaging_handoff → ImagePlate → reverse → Liconic via the existing handoff calibration ([providers/pbi_liconic/ros2_ws/src/hamilton_star_bringup/config/handoffs.yaml](providers/pbi_liconic/ros2_ws/src/hamilton_star_bringup/config/handoffs.yaml)) extended with an `imaging_handoff` site. The provider ships a sim backend that writes placeholder PNGs; a real driver swaps in via the same action.

**Operator-services sidecar:** `bb_operator` ([src/robot_skill_server/robot_skill_server/bb_operator_node.py](src/robot_skill_server/robot_skill_server/bb_operator_node.py)) exposes `/bb_operator/{add_plate, retire_plate, pause_campaign, operator_decision}` so an operator can trickle plates in and out of an active long-lived tree without restarting it. Tracks the current task via `/skill_server/task_state` and writes through SQLite WAL to the active task's persistent blackboard — same DB the executor reads.

## Skill discovery and advertisement

The architectural backbone. Every node hosting one or more skill action servers publishes one latched topic `<node_fqn>/skills`.

- **Type.** [robot_skills_msgs/msg/SkillManifest](lib/robot_skills_msgs/msg/SkillManifest.msg) wraps a list of [SkillAdvertisement](lib/robot_skills_msgs/msg/SkillAdvertisement.msg) entries, each pairing a full [SkillDescription](lib/robot_skills_msgs/msg/SkillDescription.msg) with BT-specific bindings (`bt_tag`, `goal_defaults`, `output_renames`, `post_process_id`, `input_xml_attrs`).
- **QoS.** `TRANSIENT_LOCAL` durability, `RELIABLE`, `KEEP_LAST(1)`, `LIVELINESS_AUTOMATIC` with `liveliness_lease_duration = 10s`. Late joiners receive the latched manifest; dead publishers are evicted by the discovery node's `on_liveliness_changed` callback.
- **Helpers.** [lib/robot_skill_advertise/](lib/robot_skill_advertise/) provides Python and C++ helpers so providers don't take a transitive dependency on the orchestrator. Used from Liconic, Hamilton, the Meca500 proxy, and the agent script server.
- **Discovery.** [skill_discovery.py](src/robot_skill_server/robot_skill_server/skill_discovery.py) runs on the orchestrator: 5 s timer scans `get_topic_names_and_types()` for `*/skills`, subscribes with the matching QoS, lazily imports each entry's action type, and aggregates the merged view onto `/skill_server/skill_registry`.
- **Multi-robot keying.** Runtime registry is `dict[(robot_id, bt_tag), ActionEntry]`. BT XML grows by one optional attribute on each action node: `robot_id="meca500"`. Resolution walks the parent subtree for an inherited `robot_id`, then falls back to `bt_tag` alone (parse error if ambiguous). Legacy `server_name="..."` remains a supported override.

## Behavior tree execution

[tree_executor.py](src/robot_skill_server/robot_skill_server/tree_executor.py) is a pure-Python BT.CPP-v4-compatible parser/executor. It supports:

- **Control flow** — Sequence, Fallback, Parallel, RetryUntilSuccessful, **Repeat**, **KeepRunningUntilFailure**, **WhileDoElse**, ForceSuccess/Failure, Decorators, SubTree.
- **Action nodes** — every `*/skills` advertisement registers as an XML tag. The executor reflects the action's Goal type to derive ports, applies `goal_defaults`, and runs `post_process_id` on the result before writing to the blackboard. Each action also carries an `idempotent` flag from its `SkillDescription`, used by the resume path (see "Long-lived tree resume" below).
- **Utility nodes** — `WaitForDuration`, `WaitUntil` (wall-clock, deadline-preserving across restart), `Log`, `SetBlackboard`, **`BlackboardCondition`** (gate a subtree on a persistent flag), **`PopFromQueue`** / **`PushToQueue`** (list-valued blackboard queues), **`AdvancePlate`** (post-cycle bookkeeping for the campaign tree), plus human-interaction nodes (`HumanPrompt`, `WaitForHumanResponse`).
- **Cancellation.** Terminal states are `SUCCESS` / `FAILURE` / `HALTED` (cancel publishes `HALTED`, not `CANCELLED`).
- **Long-lived tree resume.** Every control / decorator / loop node persists its tick state to a per-task SQLite DB at `~/.local/state/skill_server/tasks/{task_id}/state.db` (WAL mode). Blackboard keys prefixed `persistent.` are mirrored to the same file (type-checked at write — JSON-serialisable values only). On restart, `BtExecutor` scans for incomplete tasks and the executor re-ticks each tree from the root; every `_Checkpoint` node hydrates its index/iteration so no work past the last successful child is repeated. `RosActionNode` records `(node_path, server_name, goal_uuid, idempotent)` before submission; on resume, idempotent goals auto-resubmit, non-idempotent goals refuse and surface an alert that the operator can resolve via `/bb_operator/operator_decision`.

[bt_executor.py](src/robot_skill_server/robot_skill_server/bt_executor.py) hosts the [/skill_server/execute_behavior_tree](lib/robot_skills_msgs/action/ExecuteBehaviorTree.action) action, polls [src/robot_behaviors/trees/](src/robot_behaviors/trees/) every 2 s for changes, and publishes the latched tree list to `/skill_server/available_trees`.

[task_composer.py](src/robot_skill_server/robot_skill_server/task_composer.py) generates BT XML from an ordered list of `TaskStep`s via [/skill_server/compose_task](lib/robot_skills_msgs/srv/ComposeTask.srv). The dashboard's *Compose* mode and the MCP `compose_task` tool both call it.

## Compound and scripted skills — two surfaces, two trust levels

| Surface | Host | Lifetime | Use case |
|---|---|---|---|
| [/skill_server/register_compound_skill](lib/robot_skills_msgs/srv/RegisterCompoundSkill.srv) | Orchestrator | Persistent (`~/.ros2_robot_skills/compound_skills/`) | Vetted, reused, lab-wide skills |
| `register_script` MCP tool ([RegisterScript.srv](lib/robot_skills_msgs/srv/RegisterScript.srv)) | Agent's machine | MCP session | Ad-hoc, session-scoped, agent-authored |

The agent path uses [RunScript.action](lib/robot_skills_msgs/action/RunScript.action) — a generic action with `KeyValue[] inputs / outputs`. The script server hosts one action server per registered script at `/scripts_<session>/<name>`, and dispatches on `kind ∈ {bt_xml, action_sequence, python_callable}`. `python_callable` is gated behind `--allow-python-scripts` and only ever runs on the agent's host.

The orchestrator's `SkillDiscovery` picks up agent-host scripts the same way it picks up hardware proxies; from the orchestrator's point of view an LLM-authored skill is indistinguishable from a Liconic action. From a security point of view the orchestrator never executes agent code.

## Sim-before-real workflow

The orchestrator can execute a tree against a simulator before committing to physical hardware. Long-running plans (Liconic incubations, multi-step assays running for hours or days) get a fast pre-flight that catches parameter mistakes, missing skills, and discovery failures without burning real-world time.

**Three execution modes** on [ExecuteBehaviorTree.action](lib/robot_skills_msgs/action/ExecuteBehaviorTree.action):

| `target_mode` | Phases | Use case |
|---|---|---|
| `MODE_REAL` (default) | real | Production. Back-compat — pre-existing callers behave unchanged. |
| `MODE_SIM` | sim | One-shot dry-run; the orchestrator never touches real action servers. |
| `MODE_SIM_THEN_REAL` | sim → approval gate → real | Operator-gated promotion. Sim runs first; on success the orchestrator parks the goal and waits for an explicit approval before running the real phase. |

**Namespace pairing.** Each provider's launch takes a single new `namespace_prefix` argument (default empty for real, `/sim` for sim) which is applied via `PushRosNamespace`. The real and sim action surfaces coexist:

| Provider | Real namespace (unchanged) | Sim namespace |
|---|---|---|
| Meca500 | `/meca500/skill_atoms/*` | `/sim/meca500/skill_atoms/*` |
| Hamilton | `/hamilton_star_action_server/*` | `/sim/hamilton_star_action_server/*` |
| Liconic | `/liconic_action_server/*` | `/sim/liconic_action_server/*` |

`SkillDiscovery` filters out `/sim/*` manifest topics so the registry is single-source-of-truth on real entries. `parse_trees(..., sim_namespace_prefix="/sim")` synthesises the sim paths at parse time — no second registry, no extra `robots.yaml` plumbing, the same XML runs in both phases.

**Approval gate.** When a `MODE_SIM_THEN_REAL` sim phase succeeds, [BtExecutor](src/robot_skill_server/robot_skill_server/bt_executor.py) latches a [DryRunStatus](lib/robot_skills_msgs/msg/DryRunStatus.msg) on `/skill_server/dryrun_status` and `await`s on a future until [ApproveDryRun.srv](lib/robot_skills_msgs/srv/ApproveDryRun.srv) is called on `/skill_server/approve_dry_run`. The dashboard subscribes to the latched status and surfaces an approve/reject modal; the MCP tool surface (`get_dryrun_status`, `approve_dry_run`) and any direct ROS client can release the gate the same way. On rejection (or if the sim phase fails) the real phase is `SKIPPED` and that lands in the result's `real_final_status` field.

**Time compression.** Long-running provider operations honour an opt-in `time_compression` parameter on the sim backend so a multi-hour incubation collapses into seconds during a dry-run. Today this is wired on the [Liconic sim backend](providers/pbi_liconic/ros2_ws/src/liconic_ros/liconic_ros/sim_backend.py) (its actions return immediately, so the helper is a forward-looking lever for future long-duration skills). Meca500 and Hamilton sims already return in seconds and don't need it.

**Optional sim-variant tree.** The goal accepts an optional `sim_tree_xml` field that overrides `tree_xml` for the sim phase only — useful when the dry-run wants to elide steps that aren't worth simulating. Empty falls back to the real tree.

## Long-lived campaign workflow

For trees that must run for **weeks** (operators trickling plates through a Liconic ↔ Hamilton ↔ imaging-station cycle), the framework is designed so the tree itself carries the campaign state — there is no separate "campaign manager" service above the BT layer. Persistence is a property of every tree, not a special path.

```
┌─────────────────────────────────────────────────────────────────┐
│ Operator (browser / ROS service caller)                         │
│   /bb_operator/add_plate          /bb_operator/pause_campaign   │
│   /bb_operator/retire_plate       /bb_operator/operator_decision│
└──────────────────────────┬──────────────────────────────────────┘
                           │ writes `persistent.*` keys
                           ▼
   ┌─────────────────────────────────────────────────────────────┐
   │ SQLite per-task DB (WAL mode)                               │
   │ ~/.local/state/skill_server/tasks/{task_id}/state.db        │
   │   tables: blackboard, node_state, action_inflight, meta     │
   └──────────────────────────┬──────────────────────────────────┘
                              │ reads + writes
                              ▼
   ┌─────────────────────────────────────────────────────────────┐
   │ BtExecutor + tree_executor                                  │
   │   - Blackboard mirrors `persistent.*` to the DB             │
   │   - Sequence / Repeat / KeepRunningUntilFailure / etc.      │
   │     persist their advance points                            │
   │   - RosActionNode records inflight before submit            │
   │   - On startup: scan task DBs, hydrate, reconcile inflight  │
   └─────────────────────────────────────────────────────────────┘
```

**Building blocks.**

- **Persistent blackboard** ([persistent_blackboard.py](src/robot_skill_server/robot_skill_server/persistent_blackboard.py)) — SQLite WAL store with four tables: `blackboard` (kv), `node_state` (per-node tick state), `action_inflight` (open goals), `meta` (bt_xml_hash + timestamps). Type-checked at write; raises `PersistenceError` for non-JSON values.
- **Per-node checkpoints** — `_Checkpoint` mixin on `Sequence`, `Fallback`, `RetryUntilSuccessful`, `Repeat`, `KeepRunningUntilFailure`. Each persists the index/iteration/attempt that has *successfully completed*. On a parent advance the child's subtree state is wiped via `clear_node_state_subtree` so a future re-invocation (e.g., next Repeat iteration) re-executes rather than short-circuiting on a stale cached result.
- **Action-inflight reconciliation** — every `RosActionNode` records `(node_path, server_name, action_type, goal_uuid, idempotent)` before submitting and clears the row on terminal result. After a `skill_server` crash, the resume path inspects the row: idempotent → log warning, clear, fall through and re-submit; non-idempotent → log error with the DB path, on_skill_failed, return FAILURE so the tree halts. The operator either clears the row by hand or resolves it via `/bb_operator/operator_decision` (`retry` / `skip-as-success` / `skip-as-failure` / `abort-tree`).
- **Wall-clock primitives** — `WaitUntil timestamp="{persistent.next_due_at}"` checkpoints the deadline, so a mid-sleep crash that resumes after the deadline returns SUCCESS immediately rather than re-arming a fresh sleep.
- **Operator services** — the `bb_operator` sidecar is *thin*: each handler opens the active task's DB, mutates one or two `persistent.*` keys, closes the DB. No campaign logic — that lives in the BT.

**The campaign tree** ([src/robot_behaviors/trees/campaign/plate_imaging_campaign.xml](src/robot_behaviors/trees/campaign/plate_imaging_campaign.xml)):

```
KeepRunningUntilFailure
  └─ BlackboardCondition (key=persistent.paused, expected=false)
      └─ Sequence
          ├─ PopFromQueue   ← persistent.plate_queue → persistent.current_plate
          ├─ WaitUntil      ← timestamp = current_plate.next_due_at
          ├─ SubTree         PlateImageCycle (Liconic Fetch → iSWAP →
          │                  ImagePlate → reverse → Liconic TakeIn,
          │                  wrapped in RetryUntilSuccessful num_attempts=2)
          └─ AdvancePlate    increment cycle, recompute next_due_at,
                             requeue unless retiring or target reached
```

**Skill idempotency** is declared per-atom via `SkillDescription.idempotent` (default false). The `imaging_station` provider sets `idempotent: true` because re-imaging a plate is cheap and overwriting the previous capture is safe; motion atoms (Hamilton iSWAP, Meca500 moves) keep the conservative default so the operator-decision flow gates re-execution.

## Resource leases

[lease_broker.py](src/robot_skill_server/robot_skill_server/lease_broker.py) provides exclusive named resource leases with TTL and renewal — used to gate concurrent access to shared hardware (e.g. the deck on the Hamilton, the Meca500 arm). Services: `acquire_lease`, `renew_lease`, `release_lease`. Latched snapshot on `/skill_server/leases`; lifecycle stream on `/skill_server/lease_events`.

## Directory layout — one bucket per deployment role

| Top-level dir | Role | Runs on |
|---|---|---|
| [lib/](lib/) | Shared libraries — host-agnostic, no runtime | Consumed by every host |
| [src/](src/) | Orchestrator processes + assets | Orchestrator PC |
| [agent/](agent/) | MCP-host processes + agent-local services | Agent's machine (anywhere on DDS) |
| [providers/](providers/) | Per-robot/instrument code | The robot/instrument PC |

### lib/ — shared

- [robot_skills_msgs](lib/robot_skills_msgs/) — actions, services, messages (incl. `SkillManifest`, `RunScript`, `KeyValue`).
- [robot_skill_advertise](lib/robot_skill_advertise/) — Python + C++ advertise/discovery helpers.
- [robot_arm_skills](lib/robot_arm_skills/) — MoveIt2 arm skill library (C++ headers + 12 atom implementations under [src/](lib/robot_arm_skills/src/)) and Python rosbag skills ([rosbag_skills_node.py](lib/robot_arm_skills/robot_arm_skills/rosbag_skills_node.py) — `RecordRosbag`, `StopRecording`). Compiled into both the Meca500 and Panda proxies.

### src/ — orchestrator

- [robot_skill_server](src/robot_skill_server/) — Python orchestrator (`skill_server_node`, `skill_discovery`, `tree_executor`, `bt_executor`, `task_composer`, `lease_broker`, `skill_registry`).
- [robot_dashboard](src/robot_dashboard/) — React 18 + Vite + TypeScript + Three.js SPA. Panels: bt-tree, executor, task-monitor, skill-browser, joint-viewer, tf-viewer, plotter, logs, diagnostics, intervention, human-prompts, service-caller, topics. Talks to ROS via rosbridge over `ws://9090`.
- [robot_behaviors](src/robot_behaviors/) — XML behavior tree definitions under [trees/](src/robot_behaviors/trees/).

### agent/ — MCP host

- [robot_skill_mcp](agent/robot_skill_mcp/) — FastMCP stdio server + `mcp_ros_bridge` rclpy node. Tools: `list_skills`, `list_trees`, `compose_task`, `execute_tree`, `register_script`, `list_scripts`, `delete_script`.
- [robot_script_server](agent/robot_script_server/) — per-MCP-session scripted action server. Co-launched with `bt_executor_mcp`.

### providers/

- [meca500/src/](providers/meca500/src/) — Mecademic Meca500 6-DoF arm. Five packages: `meca500_description` / `_hardware` / `_moveit` / `_bringup` (subtree of `guyEIT/meca500_ros2`), plus the local [meca500_skill_server](providers/meca500/src/meca500_skill_server/) per-robot proxy that wraps MoveIt once and hosts all 12 arm atoms in-process.
- [panda_sim/src/](providers/panda_sim/src/) — generic 7-DoF Panda sim. [robot_sim_config](providers/panda_sim/src/robot_sim_config/) (URDF/SRDF/MoveIt config) + [robot_mock_skill_atoms](providers/panda_sim/src/robot_mock_skill_atoms/) (mock backend, fake_hardware). Used by the dashboard dev path and `lab-sim`.
- [pbi_liconic/ros2_ws/src/](providers/pbi_liconic/ros2_ws/src/) — Liconic STX44 incubator + Hamilton STAR liquid handler (subtree of `guyEIT/pbi_liconic`). Each runs a single Python action-server proxy.
- [imaging_station/src/imaging_station/](providers/imaging_station/src/imaging_station/) — generic plate imaging-station provider, **fresh in-tree (not a subtree)**. Single ament-python package implementing `robot_skills_msgs/action/ImagePlate` (declared idempotent). Sim backend writes a placeholder PNG + JSON metadata per requested site under `~/.local/state/imaging_station/{plate_name}/{epoch_ms}_{counter}/`; a real driver backend (BMG / Tecan Spark / BioTek Cytation / microscope) drops in behind the same action interface.

## Deployment topologies

| Mode | What runs where |
|---|---|
| **Distributed prod** | Orchestrator PC: `skill_server_node` + dashboard + rosbridge. Meca500 PC: `meca500_skill_server` + MoveIt. Liconic PC: `liconic_action_server` + `hamilton_star_action_server`. Agent host: anywhere on DDS. Optional: a sim instance per provider under `/sim/*` for dry-run support. |
| **`lab-sim`** | Every provider sim + skill atoms + skill_server + dashboard, single `ros2 launch` on the dev box. Atoms advertise under bare paths (no `/sim/` prefix). Validated end-to-end (hamilton 0.54s, liconic 0.54s, meca500 8.80s). |
| **★ `lab-up`** | Like `lab-sim` plus a paired `/sim/*` instance of every provider running side-by-side. Dev-box test bed for `MODE_SIM_THEN_REAL`. The "real" side still uses mock backends on a hardware-less box; the point is to exercise the namespace rewrite and the approval gate. |
| **`real-native`** | Single-box real-robot deployment on the orchestrator PC. |
| **`lite-native`** | Dashboard + orchestration dev without MoveIt; uses `robot_mock_skill_atoms`. |
| **Per-provider sim** | `meca500-sim-test` / `hamilton-sim-test` / `liconic-sim-test` — one provider in isolation. |

Per-PC pixi environments (`lite-native`, `real-native`, `orchestrator`, `meca500-host`, `liconic-host`, `lab-sim`) install only what each PC needs; all share `ros-jazzy-robot-skills-msgs` from `~/channel`.

## Live-update behavior

Edits on the host are immediately visible inside the dev container via volume mount; `colcon build --symlink-install` symlinks Python and XML share files back to `src/`. Behavior tree XMLs are auto-discovered within ~2 s; the dashboard's tree list updates over the latched topic without a refresh. Python skill server code is live on save (restart the node only if it caches state at startup). C++ atoms require `colcon build --packages-select <pkg>` + node restart. Frontend changes need `vite build` + `colcon build --symlink-install --packages-select robot_dashboard` (or `pixi run dashboard-dev` for hot reload).

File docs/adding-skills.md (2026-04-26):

# Adding Skills to the Robot Skills Framework

This guide covers how to add new capabilities to the robot. There are several levels of abstraction:

| What | Language | When to use |
|---|---|---|
| **Skill atom** | Python or C++ | A new primitive capability (e.g., "move arm", "read sensor") |
| **Mock skill atom** | C++ | Simulated version of an atom for testing without hardware |
| **BT node** | C++ | Wraps a skill atom so it can be used in behavior trees |
| **Compound skill** | XML or service call | Combines existing skills into a reusable sequence |

The typical workflow for a completely new skill: define the action interface, write the atom, add a mock, create the BT node, then use it in trees.

---

## 1. Define the action interface

Every skill communicates via a ROS2 action. Define one in `src/robot_skills_msgs/action/`.

**Example:** `src/robot_skills_msgs/action/GripperControl.action`

```
# Goal
string command              # "open", "close", "set_position"
float64 position            # 0.0=fully closed, 1.0=fully open
float64 force_limit         # Max force in Newtons, 0.0 = default
float64 speed               # 0.0-1.0
---
# Result
bool success
string message
float64 final_position
bool object_grasped
---
# Feedback
float64 current_position
float64 current_force
```

Three sections separated by `---`: what the caller sends (Goal), what it gets back (Result), and what it receives during execution (Feedback). Always include `bool success` and `string message` in the Result.

Register the new file in `src/robot_skills_msgs/CMakeLists.txt`:

```cmake
rosidl_generate_interfaces(${PROJECT_NAME}
  # ... existing actions ...
  "action/YourNewSkill.action"
  # ... existing msgs/srvs ...
)
```

Rebuild `robot_skills_msgs` before anything else — other packages depend on it.

---

## 2. Write a skill atom

### Python (recommended for most skills)

A skill atom is a ROS2 action server. Python is the simplest path.

```python
# src/robot_arm_skills/robot_arm_skills/your_skill.py

import rclpy
from rclpy.action import ActionServer, GoalResponse, CancelResponse
from rclpy.node import Node
from robot_skills_msgs.action import YourNewSkill

class YourSkillNode(Node):
    def __init__(self):
        super().__init__("your_skill_node")

        self._action_server = ActionServer(
            self,
            YourNewSkill,
            "/skill_atoms/your_skill",
            execute_callback=self._execute,
            goal_callback=self._on_goal,
            cancel_callback=self._on_cancel,
        )
        self.get_logger().info("YourSkill action server started")

    def _on_goal(self, goal_request):
        # Validate the goal. Return ACCEPT or REJECT.
        return GoalResponse.ACCEPT

    def _on_cancel(self, goal_handle):
        return CancelResponse.ACCEPT

    async def _execute(self, goal_handle):
        goal = goal_handle.request
        result = YourNewSkill.Result()
        feedback = YourNewSkill.Feedback()

        # --- Do the actual work ---
        # Publish feedback during long operations:
        feedback.progress = 0.5
        feedback.status_message = "Halfway there"
        goal_handle.publish_feedback(feedback)

        # Check for cancellation:
        if goal_handle.is_cancel_requested:
            goal_handle.canceled()
            result.success = False
            result.message = "Cancelled"
            return result

        # --- Done ---
        result.success = True
        result.message = "Completed"
        goal_handle.succeed()
        return result

def main():
    rclpy.init()
    node = YourSkillNode()
    rclpy.spin(node)
    rclpy.shutdown()
```

Add a console script entry point in `src/robot_arm_skills/setup.py` (or `setup.cfg`):

```python
entry_points={
    "console_scripts": [
        "your_skill_node = robot_arm_skills.your_skill:main",
    ],
},
```

Then add it to the launch file so it starts with the system.

### C++ (for performance-critical or hardware-driver skills)

Inherit from `SkillBase<ActionT>` in `src/robot_arm_skills/include/robot_arm_skills/skill_base.hpp`. This base class handles:
- Action server lifecycle
- Automatic registration with the skill registry
- Diagnostic publishing
- Precondition checking

```cpp
#include "robot_arm_skills/skill_base.hpp"
#include "robot_skills_msgs/action/your_new_skill.hpp"

class YourSkill
  : public robot_arm_skills::SkillBase<robot_skills_msgs::action::YourNewSkill>
{
public:
  using YourNewSkill = robot_skills_msgs::action::YourNewSkill;
  using Base = robot_arm_skills::SkillBase<YourNewSkill>;

  explicit YourSkill(const rclcpp::NodeOptions & options = rclcpp::NodeOptions())
  : Base("your_skill_node", "/skill_atoms/your_skill", options)
  {
    // Declare parameters, initialize hardware, etc.
  }

  robot_skills_msgs::msg::SkillDescription getDescription() override
  {
    robot_skills_msgs::msg::SkillDescription desc;
    desc.name = "your_skill";
    desc.display_name = "Your Skill";
    desc.description = "What this skill does, in plain language.";
    desc.category = "motion";  // motion | perception | manipulation | utility
    desc.action_type = "robot_skills_msgs/action/YourNewSkill";
    return desc;
  }

  std::shared_ptr<Result> executeGoal(
    const std::shared_ptr<GoalHandle> goal_handle) override
  {
    auto result = std::make_shared<YourNewSkill::Result>();
    const auto & goal = goal_handle->get_goal();

    // Do the work, publish feedback, check for cancellation.

    result->success = true;
    result->message = "Done";
    return result;
  }
};
```

Register in `src/robot_arm_skills/CMakeLists.txt`:

```cmake
add_executable(your_skill_node src/your_skill.cpp)
ament_target_dependencies(your_skill_node rclcpp robot_skills_msgs ...)
install(TARGETS your_skill_node DESTINATION lib/${PROJECT_NAME})
```

---

## 3. Add a mock skill atom

Mock atoms let you test behavior trees without real hardware. They live in `src/robot_mock_skill_atoms/`.

A mock should:
- Accept the same action interface as the real skill
- Simulate execution with a configurable delay
- Return plausible results (e.g., mock detection returns a fixed pose)
- Publish joint targets to `/mock/joint_target` or `/mock/gripper_target` so the TF viewer shows the robot moving

```cpp
// src/robot_mock_skill_atoms/src/mock_your_skill.cpp

class MockYourSkill
  : public robot_arm_skills::SkillBase<robot_skills_msgs::action::YourNewSkill>
{
public:
  explicit MockYourSkill(const rclcpp::NodeOptions & options)
  : Base("mock_your_skill", "/skill_atoms/your_skill", options)
  {
    this->declare_parameter("your_skill_delay", 1.0);
  }

  std::shared_ptr<Result> executeGoal(
    const std::shared_ptr<GoalHandle> goal_handle) override
  {
    auto result = std::make_shared<Result>();
    double delay = this->get_parameter("your_skill_delay").as_double();

    // Simulate with feedback
    auto feedback = std::make_shared<Feedback>();
    int steps = 10;
    for (int i = 1; i <= steps; ++i) {
      if (goal_handle->is_canceling()) {
        result->success = false;
        result->message = "Cancelled";
        return result;
      }
      feedback->progress = static_cast<double>(i) / steps;
      goal_handle->publish_feedback(feedback);
      std::this_thread::sleep_for(
        std::chrono::duration<double>(delay / steps));
    }

    result->success = true;
    result->message = "[MOCK] Your skill completed";
    return result;
  }
};

#include "rclcpp_components/register_node_macro.hpp"
RCLCPP_COMPONENTS_REGISTER_NODE(robot_mock_skill_atoms::MockYourSkill)
```

Register in `src/robot_mock_skill_atoms/CMakeLists.txt`:

```cmake
add_library(mock_your_skill SHARED src/mock_your_skill.cpp)
ament_target_dependencies(mock_your_skill ${MOCK_DEPS})
rclcpp_components_register_node(mock_your_skill
  PLUGIN "robot_mock_skill_atoms::MockYourSkill"
  EXECUTABLE mock_your_skill_node)
```

Add any configurable parameters to `src/robot_mock_skill_atoms/config/mock_params.yaml`:

```yaml
mock_your_skill:
  ros__parameters:
    your_skill_delay: 1.0
```

Add the node to the lite launch file (`src/robot_skill_server/launch/skill_server_lite.launch.py`).

---

## 4. Create a BT node wrapper

BT nodes wrap skill atoms for use in behavior trees. This part must be C++ because BehaviorTree.CPP is a C++ library.

Add your node class to `src/robot_bt_nodes/include/robot_bt_nodes/bt_skill_nodes.hpp`:

```cpp
class YourSkillNode
  : public BT::RosActionNode<robot_skills_msgs::action::YourNewSkill>
{
public:
  using YourNewSkill = robot_skills_msgs::action::YourNewSkill;

  YourSkillNode(
    const std::string & name,
    const BT::NodeConfig & config,
    const BT::RosNodeParams & params)
  : BT::RosActionNode<YourNewSkill>(name, config, params) {}

  static BT::PortsList providedPorts()
  {
    return {
      BT::InputPort<std::string>("some_param", "default_value", "Description"),
      BT::OutputPort<std::string>("some_result", "Description"),
    };
  }

  bool setGoal(Goal & goal) override
  {
    goal.some_param = getInput<std::string>("some_param").value_or("default");
    return true;
  }

  BT::NodeStatus onResultReceived(const WrappedResult & result) override
  {
    if (result.result->success) {
      setOutput("some_result", result.result->some_field);
      return BT::NodeStatus::SUCCESS;
    }
    return BT::NodeStatus::FAILURE;
  }

  BT::NodeStatus onFailure(BT::ActionNodeErrorCode error) override
  {
    RCLCPP_ERROR(logger(), "YourSkill connection/timeout error: %d",
      static_cast<int>(error));
    return BT::NodeStatus::FAILURE;
  }
};
```

Ports are how data flows in and out of BT nodes via the blackboard:
- `InputPort` reads from the blackboard or from XML attributes
- `OutputPort` writes to the blackboard for downstream nodes to read
- In XML: `some_param="literal_value"` or `some_param="{blackboard_key}"`

Register it in `src/robot_bt_nodes/src/bt_nodes_plugin.cpp` and in `src/robot_skill_server/src/bt_runner.cpp`:

```cpp
// bt_runner.cpp — in the registration section
factory.registerNodeType<robot_bt_nodes::YourSkillNode>(
  "YourSkill", make_params("/skill_atoms/your_skill"));
```

The second argument connects the BT node to the correct ROS2 action server.

---

## 5. Write behavior tree XML

Trees are written in BehaviorTree.CPP v4 XML format.

```xml
<root BTCPP_format="4" main_tree_to_execute="MyTask">
  <BehaviorTree ID="MyTask">
    <Sequence name="my_task_sequence">
      <MoveToNamedConfig name="go_observe"
                         config_name="observe"
                         velocity_scaling="0.5"/>
      <DetectObject name="find_seed"
                    object_class="seed"
                    best_object_pose="{seed_pose}"/>
      <GripperControl name="grasp"
                      command="close"
                      object_grasped="{grasped}"/>
    </Sequence>
  </BehaviorTree>
</root>
```

Key constructs:

| Node | Behaviour |
|---|---|
| `<Sequence>` | Runs children left to right. Stops on first failure. |
| `<Fallback>` | Runs children left to right. Stops on first success. |
| `<Parallel>` | Runs children concurrently. |
| `<RetryUntilSuccessful num_attempts="3">` | Retries child up to N times. |
| `<SubTree ID="OtherTree">` | Calls another tree defined in the same file. |
| `<ScriptCondition code="x == true"/>` | Evaluates a blackboard expression. |

Blackboard variables are referenced with curly braces: `target_pose="{seed_pose}"`. A node's output port writes to the blackboard, and a downstream node's input port reads from it.

Save trees in `src/robot_behaviors/trees/`. They can also be generated programmatically (see next section).

---

## 6. Create compound skills

Compound skills combine existing atoms into reusable sequences without writing C++. There are two approaches.

### Via the ComposeTask service

Call `/skill_server/compose_task` to generate BT XML from a list of steps:

```bash
ros2 service call /skill_server/compose_task robot_skills_msgs/srv/ComposeTask "{
  task_name: 'open_and_home',
  task_description: 'Open gripper then move home',
  steps: [
    {skill_name: 'gripper_control', parameters_json: '{\"command\": \"open\"}',
     input_blackboard_keys: [], output_blackboard_keys: [],
     retry_on_failure: false, max_retries: 0,
     condition_expression: '', description: 'Open gripper'},
    {skill_name: 'move_to_named_config', parameters_json: '{\"config_name\": \"home\"}',
     input_blackboard_keys: [], output_blackboard_keys: [],
     retry_on_failure: false, max_retries: 0,
     condition_expression: '', description: 'Move to home'}
  ],
  sequential: true,
  add_precondition_checks: false
}"
```

The response contains valid BT XML. You can execute it directly or register it as a compound skill.

### Register as a reusable compound skill

Call `/skill_server/register_compound_skill` with the generated XML:

```bash
ros2 service call /skill_server/register_compound_skill \
  robot_skills_msgs/srv/RegisterCompoundSkill "{
    skill_description: {
      name: 'open_and_home',
      display_name: 'Open and Home',
      description: 'Opens the gripper and moves the arm to the home configuration.',
      category: 'compound',
      is_compound: true
    },
    bt_xml: '<root ...>...</root>',
    persist: true
  }"
```

Setting `persist: true` saves the skill to disk (`~/.ros2_robot_skills/compound_skills/`). It will be available across restarts. The skill then appears in `GetSkillDescriptions` alongside atom skills and can be used in further compositions.

### Via the dashboard

The Execute panel's "Compose" mode provides a UI for building task steps from registered skills. Select skills, set parameters, click "Compose BT XML", then execute or save.

---

## 7. File checklist

### New atom skill (full stack)

```
src/robot_skills_msgs/action/YourSkill.action          # action definition
src/robot_skills_msgs/CMakeLists.txt                    # register in rosidl_generate_interfaces

src/robot_arm_skills/your_skill.py (or .cpp)           # action server implementation
src/robot_arm_skills/setup.py (or CMakeLists.txt)      # build registration

src/robot_mock_skill_atoms/src/mock_your_skill.cpp      # mock implementation
src/robot_mock_skill_atoms/config/mock_params.yaml      # mock parameters
src/robot_mock_skill_atoms/CMakeLists.txt               # build registration

src/robot_bt_nodes/include/.../bt_skill_nodes.hpp       # BT node class
src/robot_bt_nodes/src/bt_nodes_plugin.cpp              # plugin registration
src/robot_skill_server/src/bt_runner.cpp                # bt_runner registration

src/robot_skill_server/launch/skill_server_lite.launch.py  # add mock node
src/robot_skill_server/launch/skill_server.launch.py       # add real node
```

### New compound skill (no code changes)

```
# Option A: service call
ros2 service call /skill_server/compose_task ...
ros2 service call /skill_server/register_compound_skill ...

# Option B: manual XML
src/robot_behaviors/trees/your_task.xml
```

### New mock only (for existing skill)

```
src/robot_mock_skill_atoms/src/mock_your_skill.cpp
src/robot_mock_skill_atoms/config/mock_params.yaml
src/robot_mock_skill_atoms/CMakeLists.txt
src/robot_skill_server/launch/skill_server_lite.launch.py
```

---

## 8. Build and test

```bash
# Rebuild messages first (other packages depend on them)
pixi run build  # or: docker exec ... colcon build

# Test a specific package
docker exec ros2_robot_skills_lite bash -c \
  "source /opt/ros/jazzy/setup.bash && cd /home/ws && \
   colcon build --packages-select robot_skills_msgs robot_mock_skill_atoms robot_bt_nodes robot_skill_server"

# Restart to pick up changes
pixi run lite-restart

# Verify your skill atom is running
ros2 action list | grep your_skill

# Test the BT node directly
cat > /tmp/test.xml << 'EOF'
<root BTCPP_format="4" main_tree_to_execute="Test">
  <BehaviorTree ID="Test">
    <YourSkill name="test" some_param="value"/>
  </BehaviorTree>
</root>
EOF

ros2 run robot_skill_server bt_runner --tree-file /tmp/test.xml --tick-rate 10 --task-id test1
```

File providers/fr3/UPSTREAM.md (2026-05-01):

# FR3 provider — upstream provenance

Cherry-picked from upstream Franka Robotics repos. We deliberately did **not**
`git subtree add` the whole repos: `franka_ros2` ships ~10 packages and we
only need 6, and pulling the whole tree would carry Gazebo / mobile-base /
multi-arm code we don't run here.

Trade-off: `git subtree pull` is unavailable. To re-sync with upstream, clone
the source repos at the SHAs (or newer) listed below and re-copy the listed
paths. Diff against the local divergences flagged in **Local edits** before
overwriting.

## Sources

| Source | SHA | Paths copied | Local destination |
|---|---|---|---|
| `github.com/frankarobotics/franka_description` `main` | `72baf5bf4e88eaec27f0eb61be1b20a001abf2ab` | trimmed: only `robots/{fr3,common}/`, `end_effectors/{franka_hand,common}/`, `meshes/robots/fr3/`, `meshes/robot_ee/franka_hand_*/`, `launch/`, `rviz/`, `scripts/`. Other robot models (fer, fp3, fr3v2*, tmrv0_2, mobile_fr3_duo*, fr3_duo) and accessories meshes were dropped to keep the package under 30 MB. | `providers/fr3/src/franka_description/` |
| `github.com/frankarobotics/franka_ros2` `jazzy` | `79e55bfaf1702b0c73d469bb45f24162859e6580` | `franka_msgs/`, `franka_hardware/`, `franka_semantic_components/`, `franka_robot_state_broadcaster/`, `franka_gripper/`, `franka_fr3_moveit_config/` (whole packages, no edits) | `providers/fr3/src/{franka_msgs,franka_hardware,franka_semantic_components,franka_robot_state_broadcaster,franka_gripper,franka_fr3_moveit_config}/` |
| `libfranka` | conda-forge `libfranka 0.21.1` (`hf20a59c_1`) | NONE — pulled in as a binary conda dep (`libfranka >=0.21.1` in `feature.fr3-host` / `feature.lab-sim`).  | (env-prefix only, never on disk) |

## Local edits

Edits we made on top of the cherry-picked sources:

- **Per-package `pixi.toml`** added to each cherry-picked package so they
  build via `pixi-build-ros` with the right input globs (`urdf/**`,
  `meshes/**`, `config/**`, `launch/**`, etc.). These are pure additions —
  they don't conflict with `git subtree pull` since upstream doesn't ship
  pixi metadata.
- **No xacro / URDF / hardware-plugin edits.** Upstream's
  `robots/common/franka_arm.ros2_control.xacro` already swaps between
  `mock_components/GenericSystem` and `franka_hardware/FrankaHardwareInterface`
  via the `use_fake_hardware` xacro arg — no equivalent of the Meca500
  `<xacro:if simulation>` patch is needed.

## Packages we add on top (not from upstream)

These are local-only, won't ever come from upstream:

- `providers/fr3/src/fr3_bringup/` — wrapper launch translating
  `simulation:=true/false` to `use_fake_hardware:=true/false`, plus a
  sim-specific `fr3_ros_controllers_sim.yaml` that uses position command
  interfaces (mock_components doesn't simulate effort dynamics).
- `providers/fr3/src/fr3_skill_server/` — proxy that composes 12
  `robot_arm_skills` atoms under `/fr3` plus the FrankaGripperSkill.
- `providers/fr3/src/franka_gripper_skill/` — bridges
  `robot_skills_msgs/FrankaGripperControl` onto `franka_gripper`'s
  `Move`/`Grasp`/`Homing` actions; STOP cancels the in-flight upstream goal.

## Refresh procedure

```bash
# 1. Clone upstream at desired SHAs into a scratch dir.
git clone https://github.com/frankarobotics/franka_description /tmp/fr3_upstream/desc
git clone --branch jazzy https://github.com/frankarobotics/franka_ros2 /tmp/fr3_upstream/ros2

# 2. Diff against local. Anything outside of pixi.toml, fr3_bringup/,
#    fr3_skill_server/, franka_gripper_skill/ should match upstream.
diff -ruN /tmp/fr3_upstream/desc providers/fr3/src/franka_description \
  --exclude=.git --exclude=pixi.toml | less
# (likewise for franka_ros2 packages)

# 3. Re-copy paths listed in the table above; preserve our pixi.toml files.
# 4. Update the SHAs in this file and in the commit message.
```

If upstream changes `franka_arm.ros2_control.xacro` (the sim/real switch),
re-validate `pixi run fr3-sim-test` and `pixi run fr3-moveit-run` after the
refresh — those are the load-bearing assumptions.

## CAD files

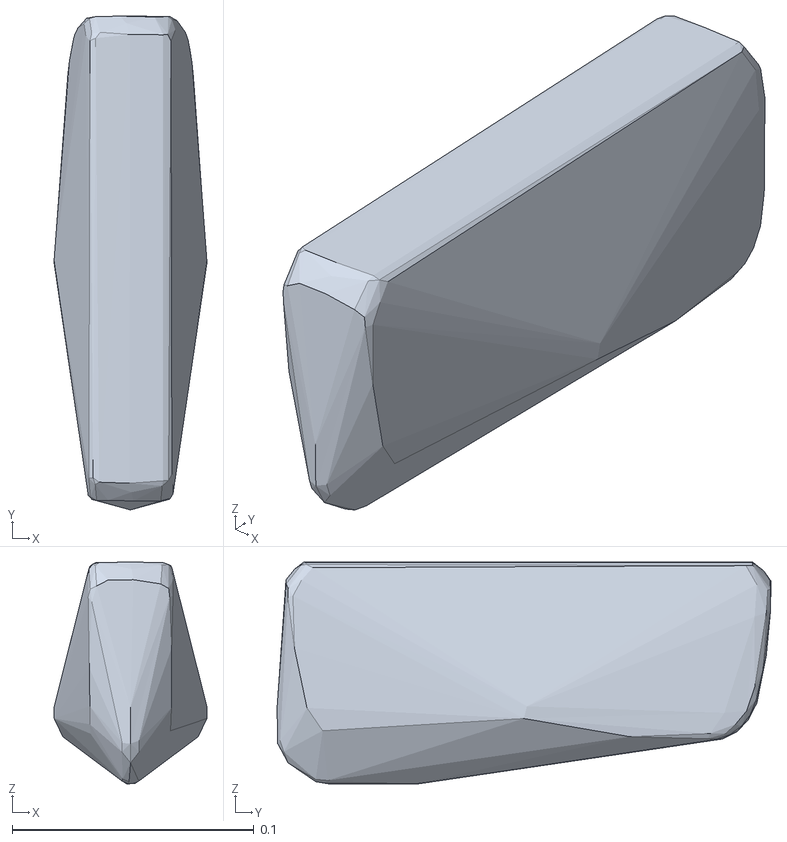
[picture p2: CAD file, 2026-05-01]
providers/fr3/src/franka_description/meshes/robot_ee/franka_hand_black/collision/hand.stl
0.0633 x 0.204 x 0.0919

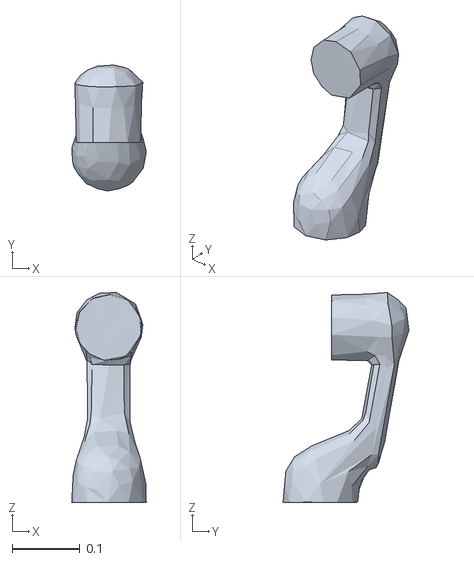
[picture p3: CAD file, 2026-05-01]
providers/fr3/src/franka_description/meshes/robots/fr3/collision/link5.stl
0.11 x 0.186 x 0.311

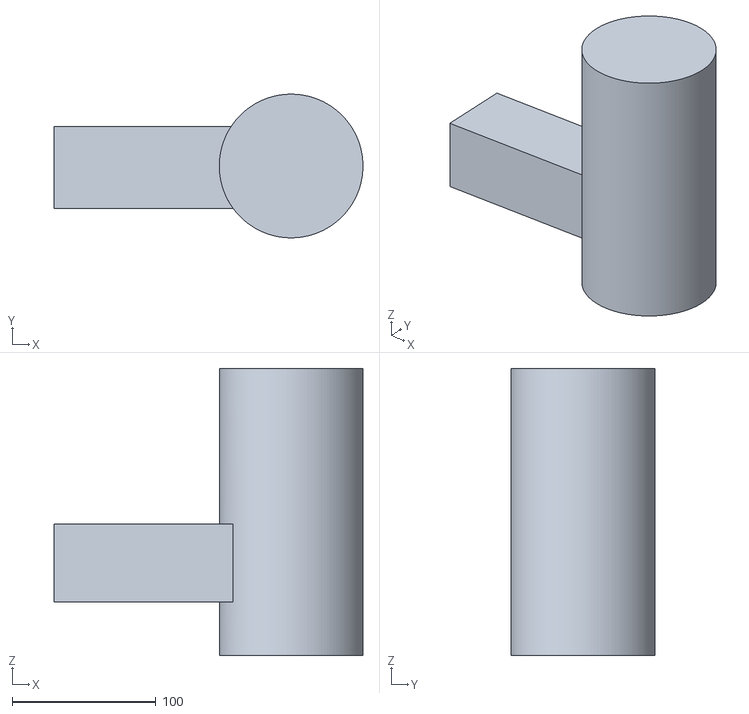
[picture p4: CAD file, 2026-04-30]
providers/imaging_station/models/microscope-camera.stl
215.0 x 100.0 x 200.0

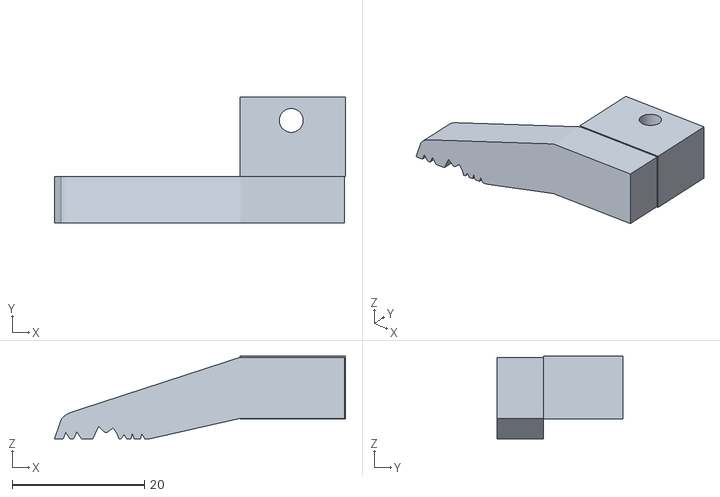
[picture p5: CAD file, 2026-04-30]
providers/meca500/seed_gripper-Finger.stl
43.9 x 19.0 x 12.5

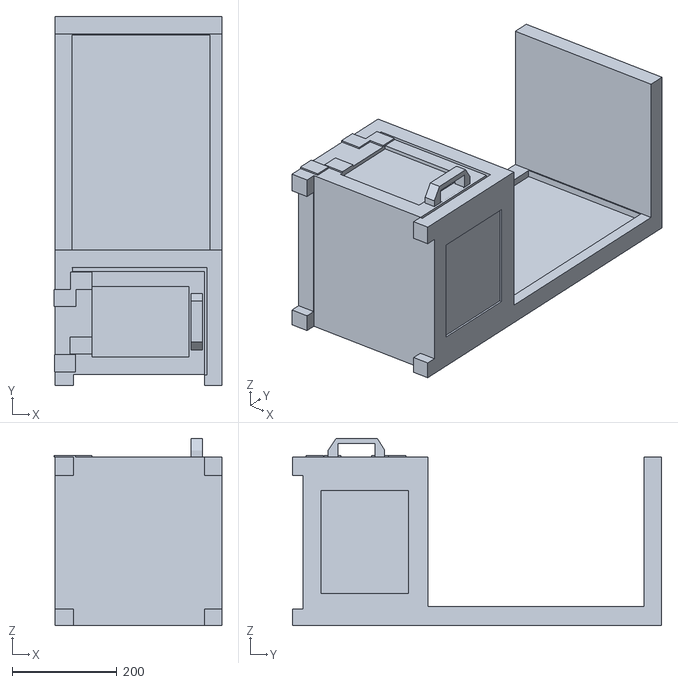
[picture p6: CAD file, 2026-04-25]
providers/meca500/src/meca500_bringup/meshes/mecatable_simple.stl
320.3 x 705.0 x 358.2

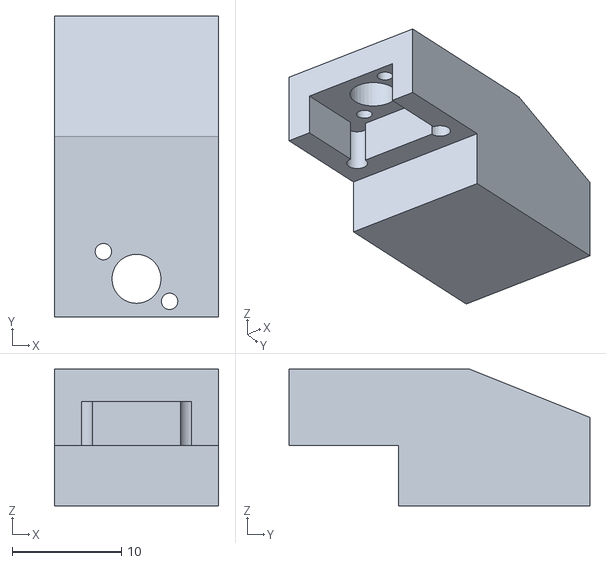
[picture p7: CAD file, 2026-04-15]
providers/meca500/src/meca500_description/meshes/collision/schunk_megp25e_finger.stl
15.0 x 27.5 x 12.5

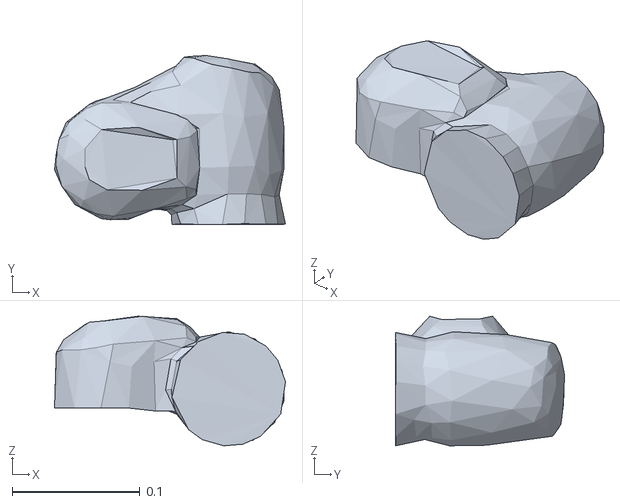
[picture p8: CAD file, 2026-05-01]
providers/fr3/src/franka_description/meshes/robots/fr3/collision/link6.stl
0.181 x 0.132 x 0.102

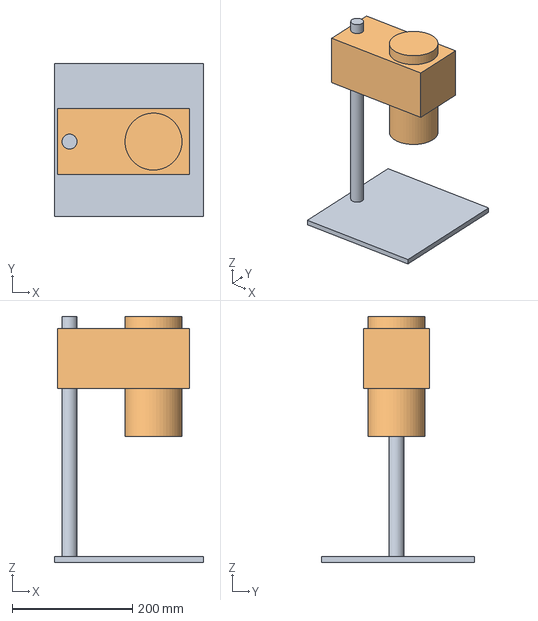
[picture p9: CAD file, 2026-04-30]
providers/imaging_station/models/microscope.FCStd
249.0 x 255.7 x 410.0 mm
stand
camera

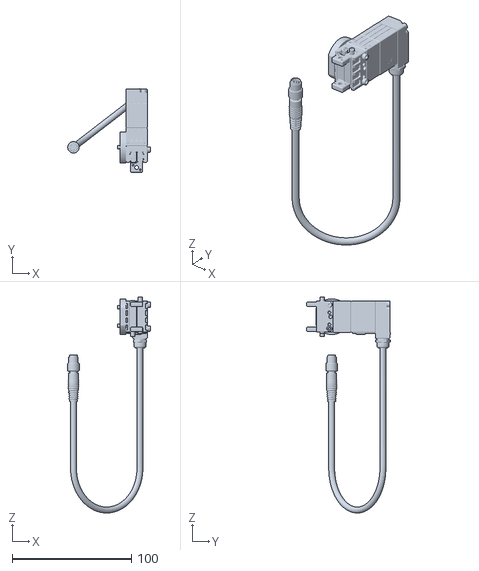
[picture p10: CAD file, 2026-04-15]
providers/meca500/src/meca500_description/meshes/collision/schunk_megp25e_body.stl
69.3 x 70.1 x 181.1

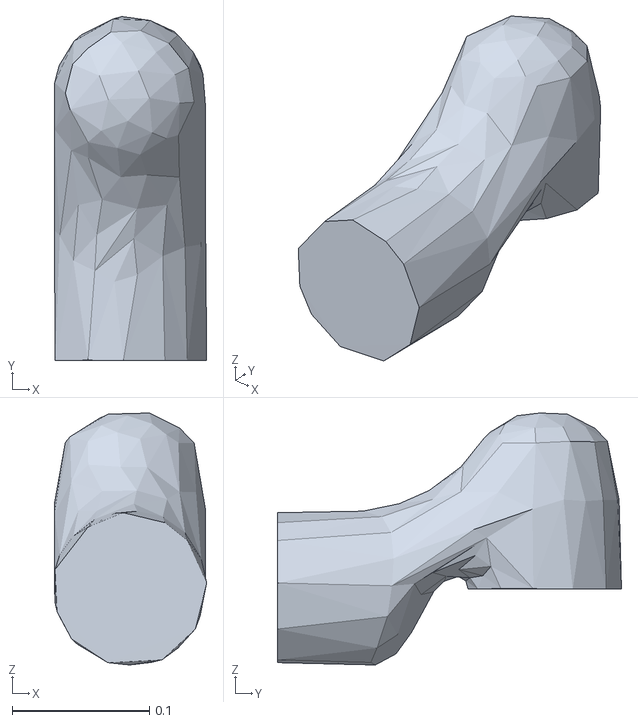
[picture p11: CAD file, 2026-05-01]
providers/fr3/src/franka_description/meshes/robots/fr3/collision/link2.stl
0.111 x 0.25 x 0.183

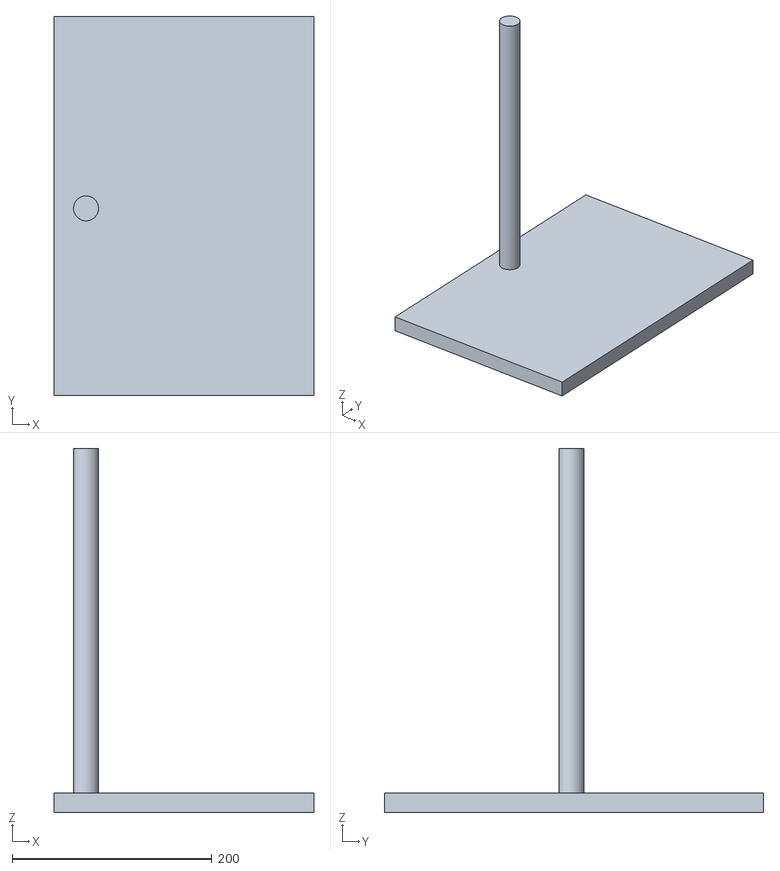
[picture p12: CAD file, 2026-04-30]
providers/imaging_station/models/microscope-stand.stl
260.0 x 380.0 x 364.6

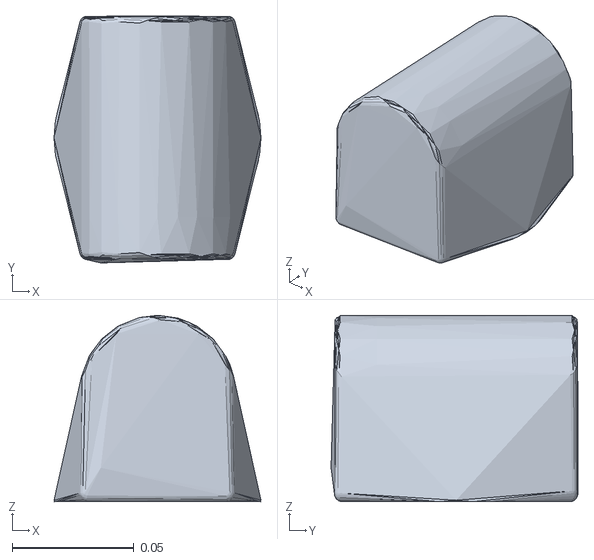
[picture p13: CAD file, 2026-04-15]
providers/meca500/src/meca500_description/meshes/collision/meca_500_r3_j1.stl
0.085 x 0.101 x 0.0765

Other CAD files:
providers/meca500/seed_gripper-Finger-right.stl
providers/fr3/src/franka_description/meshes/robots/fr3/collision/link0.stl
providers/fr3/src/franka_description/meshes/robots/fr3/collision/link1.stl
providers/fr3/src/franka_description/meshes/robots/fr3/collision/link3.stl
providers/fr3/src/franka_description/meshes/robots/fr3/collision/link4.stl
providers/fr3/src/franka_description/meshes/robots/fr3/collision/link7.stl
providers/meca500/src/meca500_description/meshes/collision/meca_500_r3_base.stl
providers/meca500/src/meca500_description/meshes/collision/meca_500_r3_j2.stl
providers/meca500/src/meca500_description/meshes/collision/meca_500_r3_j3.stl
providers/meca500/src/meca500_description/meshes/collision/meca_500_r3_j4.stl
providers/meca500/src/meca500_description/meshes/collision/meca_500_r3_j5.stl
providers/meca500/src/meca500_description/meshes/collision/meca_500_r3_j6.stl

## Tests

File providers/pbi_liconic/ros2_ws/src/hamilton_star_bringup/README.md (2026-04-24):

# hamilton_star_bringup

Launch files, deck config, and systemd unit for the Hamilton STAR ROS 2 action server.

## Don't kill the server casually

Every cold start of the action server calls `pylabrobot`'s `LiquidHandler.setup()`, which triggers a **full end-stops calibration** on the Hamilton Microlab STAR. That takes a minute or two and puts wear on the mechanics. So:

- Keep the process running across sessions — it holds the USB link open.
- Use the `AbortMotion` service (not `Ctrl-C`) to stop an in-progress goal.
- Use `ResetError` (with an acknowledgment string) to clear the `Error` state.
- Only restart the systemd unit when you've genuinely lost the hardware (USB drop, firmware hang).

## systemd install

```bash
sudo cp ~/code/plr/ros2_ws/src/hamilton_star_bringup/systemd/hamilton-star-action-server.service \
        /etc/systemd/system/
sudo systemctl daemon-reload
sudo systemctl enable hamilton-star-action-server.service
sudo systemctl start hamilton-star-action-server.service
journalctl -u hamilton-star-action-server.service -f
```

The unit depends on `/dev/hamilton_star` being present — install the
project's udev rule first (`99-hamilton.rules`) so the symlink appears
when the STAR is plugged in.

## Manual launch (dev)

```bash
cd ~/code/plr
pixi run --environment ros2 colcon build --symlink-install   # one-time
pixi run --environment ros2 ros2 launch hamilton_star_bringup action_server.launch.py \
    deck_file:=$PWD/ros2_ws/src/hamilton_star_bringup/config/star_deck.json
```

## Seed the deck

```bash
pixi run --environment ros2 python - <<'PY' > ros2_ws/src/hamilton_star_bringup/config/star_deck.json
import json
from pylabrobot.resources.hamilton import STARDeck
print(json.dumps(STARDeck(core_grippers="1000uL-5mL-on-waste").serialize()))
PY
```

Then edit the JSON to add plate carriers, tip racks, plates, etc., or
serialize from a scripted deck-assembly pass via `~/serialize_deck`.

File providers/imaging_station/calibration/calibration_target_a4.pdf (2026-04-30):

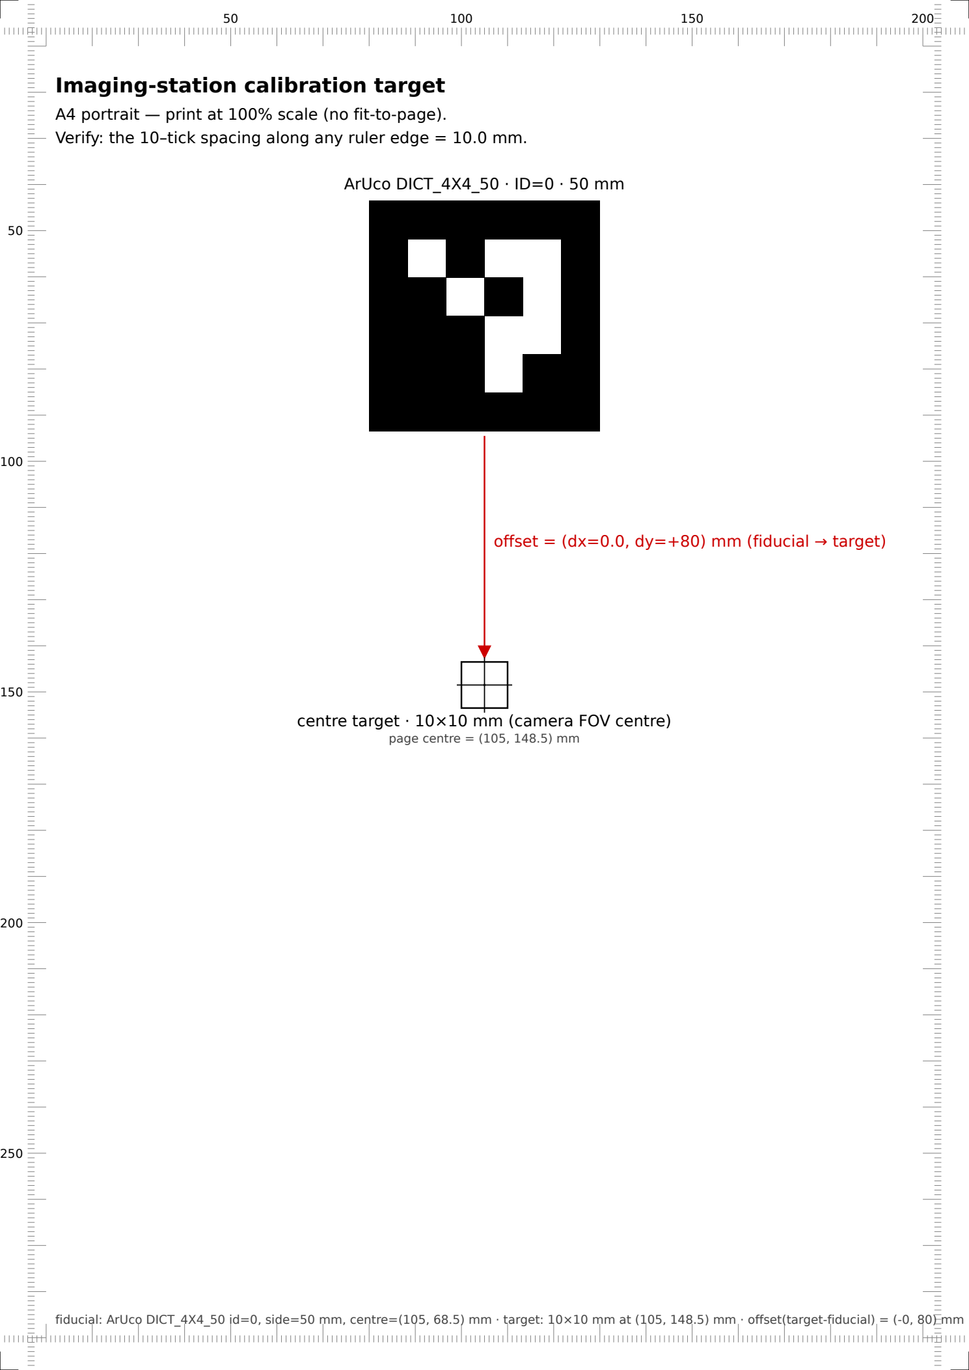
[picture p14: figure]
Imaging-station calibration target; ArUco DICT_4X4_50 · ID=0 · 50 mm; page centre = (105, 148.5) mm

A4 portrait — print at 100% scale (no fit-to-page).
Verify: the 10–tick spacing along any ruler edge = 10.0 mm.

offset = (dx=0.0, dy=+80) mm (fiducial → target)

centre target · 10×10 mm (camera FOV centre)

fiducial: ArUco DICT_4X4_50 id=0, side=50 mm, centre=(105, 68.5) mm · target: 10×10 mm at (105, 148.5) mm · offset(target-fiducial) = (-0, 80) mm

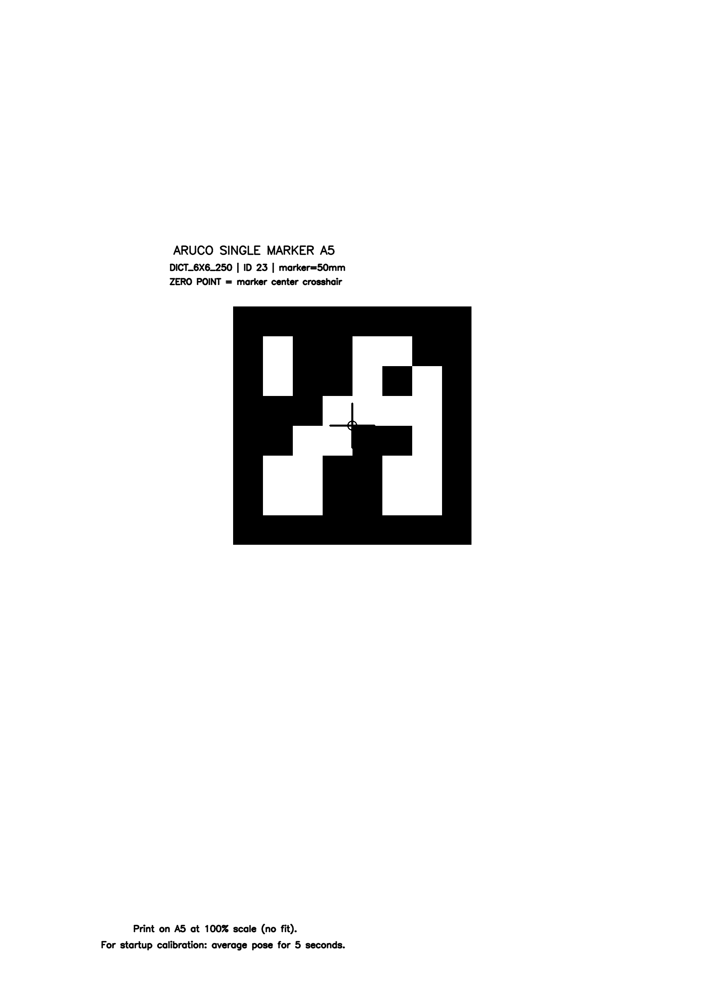
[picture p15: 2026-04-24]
providers/meca500/src/meca500_bringup/config/aruco_single_a5_50mm_id23.png

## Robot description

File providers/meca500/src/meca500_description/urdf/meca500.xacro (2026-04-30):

<robot name="meca500_arm" xmlns:xacro="http://ros.org/wiki/xacro">
  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
  <xacro:arg name="use_seed_gripper" default="false" />
  <xacro:arg name="left_mesh" default="" />
  <xacro:arg name="right_mesh" default="" />
  <xacro:arg name="stl_scale" default="0.001" />
  <xacro:arg name="left_xyz_x" default="0.0" />
  <xacro:arg name="left_xyz_y" default="0.0" />
  <xacro:arg name="left_xyz_z" default="0.0" />
  <xacro:arg name="left_rpy_r" default="0.0" />
  <xacro:arg name="left_rpy_p" default="0.0" />
  <xacro:arg name="left_rpy_y" default="0.0" />
  <xacro:arg name="right_xyz_x" default="0.0" />
  <xacro:arg name="right_xyz_y" default="0.0" />
  <xacro:arg name="right_xyz_z" default="0.0" />
  <xacro:arg name="right_rpy_r" default="0.0" />
  <xacro:arg name="right_rpy_p" default="0.0" />
  <xacro:arg name="right_rpy_y" default="0.0" />
  <xacro:arg name="grip_xyz_x" default="0.0" />
  <xacro:arg name="grip_xyz_y" default="0.0" />
  <xacro:arg name="grip_xyz_z" default="0.0" />
  <xacro:arg name="grip_rpy_r" default="0.0" />
  <xacro:arg name="grip_rpy_p" default="0.0" />
  <xacro:arg name="grip_rpy_y" default="0.0" />

  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
  <link name="meca_base_link">
    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
  </link>

  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
  <link name="meca_axis_1_link">
    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
  </link>

  <joint name="joint1" type="revolute">
    <origin xyz="0.012498 0 0.091" rpy="0 0 0" />
    <parent link="meca_base_link" />
    <child link="meca_axis_1_link" />
    <axis xyz="0 0 1" />
    <limit effort="10.0" velocity="2.61799" lower="-3.05433" upper="3.05433" />
  </joint>

  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
  <link name="meca_axis_2_link">
    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
  </link>

  <joint name="joint2" type="revolute">
    <origin xyz="0 0 0.044" rpy="0 0 0" />
    <parent link="meca_axis_1_link" />
    <child link="meca_axis_2_link" />
    <axis xyz="0 1 0" />
    <limit effort="10.0" velocity="2.61799" lower="-1.22173048" upper="1.5708" />
  </joint>

  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
  <link name="meca_axis_3_link">
    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
  </link>

  <joint name="joint3" type="revolute">
    <origin xyz="0 0 0.135" rpy="0 0 0" />
    <parent link="meca_axis_2_link" />
    <child link="meca_axis_3_link" />
    <axis xyz="0 1 0" />
    <limit effort="10.0" velocity="3.14159" lower="-2.35619" upper="1.22173048" />
  </joint>

  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
  <link name="meca_axis_4_link">
    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
  </link>

  <joint name="joint4" type="revolute">
    <origin xyz="0 0 0.038" rpy="0 0 0" />
    <parent link="meca_axis_3_link" />
    <child link="meca_axis_4_link" />
    <axis xyz="1 0 0" />
    <limit effort="10.0" velocity="5.23599" lower="-2.96706" upper="2.96706" />
  </joint>

  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
  <link name="meca_axis_5_link">
    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
  </link>

  <joint name="joint5" type="revolute">
    <origin xyz="0.12 0 0" rpy="0 0 0" />
    <parent link="meca_axis_4_link" />
    <child link="meca_axis_5_link" />
    <axis xyz="0 1 0" />
    <limit effort="10.0" velocity="5.23599" lower="-2.00713" upper="2.00713" />
  </joint>

  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
  <link name="meca_axis_6_link">
    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
  </link>

  <joint name="joint6" type="revolute">
    <origin xyz="0.07 0 0" rpy="0 0 0" />
    <parent link="meca_axis_5_link" />
    <child link="meca_axis_6_link" />
    <axis xyz="1 0 0" />
    <limit effort="10.0" velocity="8.72665" lower="-3.14159" upper="3.14159" />
  </joint>

  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
  <link name="meca_gripper_link">
    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
  </link>

  <joint name="meca_gripper_joint" type="fixed">
    <origin xyz="0 0 0" rpy="0 0 0" />
    <parent link="meca_axis_6_link" />
    <child link="meca_gripper_link" />
  </joint>

  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
  <link name="meca_gripper_finger1">
    <xacro:unless value="$(arg use_seed_gripper)">
      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
    </xacro:unless>
  </link>

  <joint name="meca_gripper_finger1_joint" type="prismatic">
    <origin xyz=".01395 .0125 -.0170205" rpy="-1.570796 0 0" />
    <parent link="meca_gripper_link" />
    <child link="meca_gripper_finger1" />
    <axis xyz="0 0 1" />
    <limit lower="0" upper="0.0055" effort="1.0" velocity="0.1" />
  </joint>

  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
  <link name="meca_gripper_finger2">
    <xacro:unless value="$(arg use_seed_gripper)">
      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
    </xacro:unless>
  </link>

  <joint name="meca_gripper_finger2_joint" type="prismatic">
    <origin xyz=".01395 -.0125 -.0170205" rpy="-1.570796 0 -3.141593" />
    <parent link="meca_gripper_link" />
    <child link="meca_gripper_finger2" />
    <axis xyz="0 0 1" />
    <limit lower="0" upper="0.0055" effort="1.0" velocity="0.1" />
    <mimic joint="meca_gripper_finger1_joint" multiplier="1.0" offset="0.0" />
  </joint>

  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
  <link name="gripper_tip_link" />

  <joint name="gripper_tip_joint" type="fixed">
    <origin xyz="0.04 0 -0.017" rpy="-1.5708 0 0" />
    <parent link="meca_gripper_link" />
    <child link="gripper_tip_link" />
  </joint>

  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
  <xacro:if value="$(arg use_seed_gripper)">
    <link name="seed_finger_left">
      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
    </link>
    <joint name="seed_finger_left_joint" type="fixed">
      <origin xyz="$(arg left_xyz_x) $(arg left_xyz_y) $(arg left_xyz_z)" rpy="$(arg left_rpy_r) $(arg left_rpy_p) $(arg left_rpy_y)" />
      <parent link="meca_gripper_finger1" />
      <child link="seed_finger_left" />
    </joint>

    <link name="seed_finger_right">
      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
    </link>
    <joint name="seed_finger_right_joint" type="fixed">
      <origin xyz="$(arg right_xyz_x) $(arg right_xyz_y) $(arg right_xyz_z)" rpy="$(arg right_rpy_r) $(arg right_rpy_p) $(arg right_rpy_y)" />
      <parent link="meca_gripper_finger2" />
      <child link="seed_finger_right" />
    </joint>

    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
    <link name="seed_gripper_tip_link" />
    <joint name="seed_gripper_tip_joint" type="fixed">
      <origin xyz="$(arg grip_xyz_x) $(arg grip_xyz_y) $(arg grip_xyz_z)" rpy="$(arg grip_rpy_r) $(arg grip_rpy_p) $(arg grip_rpy_y)" />
      <parent link="meca_gripper_link" />
      <child link="seed_gripper_tip_link" />
    </joint>
  </xacro:if>

</robot>

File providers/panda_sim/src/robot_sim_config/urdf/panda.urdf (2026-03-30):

<?xml version="1.0" ?>
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
<robot name="panda">
  <link name="panda_link0">
    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
    <inertial>
      <origin rpy="0 0 0" xyz="-0.041018 -0.00014 0.049974"/>
      <mass value="0.629769"/>
      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
    </inertial>
  </link>
  <link name="panda_link1">
    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
    <inertial>
      <origin rpy="0 0 0" xyz="0.003875 0.002081 -0.04762"/>
      <mass value="4.970684"/>
      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
    </inertial>
  </link>
  <joint name="panda_joint1" type="revolute">
    <safety_controller k_position="100.0" k_velocity="40.0" soft_lower_limit="-2.8973" soft_upper_limit="2.8973"/>
    <origin rpy="0 0 0" xyz="0 0 0.333"/>
    <parent link="panda_link0"/>
    <child link="panda_link1"/>
    <axis xyz="0 0 1"/>
    <limit effort="87" lower="-2.9671" upper="2.9671" velocity="2.3925"/>
    <dynamics D="1" K="7000" damping="0.003" friction="0.0" mu_coulomb="0" mu_viscous="16"/>
  </joint>
  <link name="panda_link2">
    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
    <inertial>
      <origin rpy="0 0 0" xyz="-0.003141 -0.02872 0.003495"/>
      <mass value="0.646926"/>
      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
    </inertial>
  </link>
  <joint name="panda_joint2" type="revolute">
    <safety_controller k_position="100.0" k_velocity="40.0" soft_lower_limit="-1.7628" soft_upper_limit="1.7628"/>
    <origin rpy="-1.57079632679 0 0" xyz="0 0 0"/>
    <parent link="panda_link1"/>
    <child link="panda_link2"/>
    <axis xyz="0 0 1"/>
    <limit effort="87" lower="-1.8326" upper="1.8326" velocity="2.3925"/>
    <dynamics D="1" K="7000" damping="0.003" friction="0.0" mu_coulomb="0" mu_viscous="16"/>
  </joint>
  <link name="panda_link3">
    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
    <inertial>
      <origin rpy="0 0 0" xyz="2.7518E-2 3.9252E-2 -6.6502E-2"/>
      <mass value="3.228604"/>
      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
    </inertial>
  </link>
  <joint name="panda_joint3" type="revolute">
    <safety_controller k_position="100.0" k_velocity="40.0" soft_lower_limit="-2.8973" soft_upper_limit="2.8973"/>
    <origin rpy="1.57079632679 0 0" xyz="0 -0.316 0"/>
    <parent link="panda_link2"/>
    <child link="panda_link3"/>
    <axis xyz="0 0 1"/>
    <limit effort="87" lower="-2.9671" upper="2.9671" velocity="2.3925"/>
    <dynamics D="1" K="7000" damping="0.003" friction="0.0" mu_coulomb="0" mu_viscous="16"/>
  </joint>
  <link name="panda_link4">
    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
    <inertial>
      <origin rpy="0 0 0" xyz="-5.317E-2 1.04419E-1 2.7454E-2"/>
      <mass value="3.587895"/>
      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
    </inertial>
  </link>
  <joint name="panda_joint4" type="revolute">
    <safety_controller k_position="100.0" k_velocity="40.0" soft_lower_limit="-3.0718" soft_upper_limit="0.0175"/>
    <origin rpy="1.57079632679 0 0" xyz="0.0825 0 0"/>
    <parent link="panda_link3"/>
    <child link="panda_link4"/>
    <axis xyz="0 0 1"/>
    <limit effort="87" lower="-3.1416" upper="0.0873" velocity="2.3925"/>
    <dynamics D="1" K="7000" damping="0.003" friction="0.0" mu_coulomb="0" mu_viscous="16"/>
  </joint>
  <link name="panda_link5">
    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
    <inertial>
      <origin rpy="0 0 0" xyz="-1.1953E-2 4.1065E-2 -3.8437E-2"/>
      <mass value="1.225946"/>
      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
    </inertial>
  </link>
  <joint name="panda_joint5" type="revolute">
    <safety_controller k_position="100.0" k_velocity="40.0" soft_lower_limit="-2.8973" soft_upper_limit="2.8973"/>
    <origin rpy="-1.57079632679 0 0" xyz="-0.0825 0.384 0"/>
    <parent link="panda_link4"/>
    <child link="panda_link5"/>
    <axis xyz="0 0 1"/>
    <limit effort="12" lower="-2.9671" upper="2.9671" velocity="2.8710"/>
    <dynamics D="1" K="7000" damping="0.003" friction="0.0" mu_coulomb="0" mu_viscous="16"/>
  </joint>
  <link name="panda_link6">
    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
    <inertial>
      <origin rpy="0 0 0" xyz="6.0149E-2 -1.4117E-2 -1.0517E-2"/>
      <mass value="1.666555"/>
      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
    </inertial>
  </link>
  <joint name="panda_joint6" type="revolute">
    <safety_controller k_position="100.0" k_velocity="40.0" soft_lower_limit="-0.0175" soft_upper_limit="3.7525"/>
    <origin rpy="1.57079632679 0 0" xyz="0 0 0"/>
    <parent link="panda_link5"/>
    <child link="panda_link6"/>
    <axis xyz="0 0 1"/>
    <limit effort="12" lower="-0.0873" upper="3.8223" velocity="2.8710"/>
    <dynamics D="1" K="7000" damping="0.003" friction="0.0" mu_coulomb="0" mu_viscous="16"/>
  </joint>
  <link name="panda_link7">
    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
    <inertial>
      <origin rpy="0 0 0" xyz="1.0517E-2 -4.252E-3 6.1597E-2"/>
      <mass value="7.35522E-1"/>
      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
    </inertial>
  </link>
  <joint name="panda_joint7" type="revolute">
    <safety_controller k_position="100.0" k_velocity="40.0" soft_lower_limit="-2.8973" soft_upper_limit="2.8973"/>
    <origin rpy="1.57079632679 0 0" xyz="0.088 0 0"/>
    <parent link="panda_link6"/>
    <child link="panda_link7"/>
    <axis xyz="0 0 1"/>
    <limit effort="12" lower="-2.9671" upper="2.9671" velocity="2.8710"/>
    <dynamics D="1" K="7000" damping="0.003" friction="0.0" mu_coulomb="0" mu_viscous="16"/>
  </joint>
  <link name="panda_link8"/>
  <joint name="panda_joint8" type="fixed">
    <origin rpy="0 0 0" xyz="0 0 0.107"/>
    <parent link="panda_link7"/>
    <child link="panda_link8"/>
    <axis xyz="0 0 0"/>
  </joint>
  <joint name="panda_hand_joint" type="fixed">
    <parent link="panda_link8"/>
    <child link="panda_hand"/>
    <origin rpy="0 0 -0.785398163397" xyz="0 0 0"/>
  </joint>
  <link name="panda_hand">
    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
    <inertial>
      <origin rpy="0 0 0" xyz="-0.01 0 0.03"/>
      <mass value="0.73"/>
      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
    </inertial>
  </link>
  <link name="panda_leftfinger">
    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
    <inertial>
      <origin rpy="0 0 0" xyz="0 0 0"/>
      <mass value="0.015"/>
      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
    </inertial>
  </link>
  <link name="panda_rightfinger">
    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
    <inertial>
      <origin rpy="0 0 0" xyz="0 0 0"/>
      <mass value="0.15"/>
      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
    </inertial>
  </link>
  <joint name="panda_finger_joint1" type="prismatic">
    <parent link="panda_hand"/>
    <child link="panda_leftfinger"/>
    <origin rpy="0 0 0" xyz="0 0 0.0584"/>
    <axis xyz="0 1 0"/>
    <limit effort="20" lower="0.0" upper="0.04" velocity="0.2"/>
    <dynamics damping="0.3"/>
  </joint>
  <joint name="panda_finger_joint2" type="prismatic">
    <parent link="panda_hand"/>
    <child link="panda_rightfinger"/>
    <origin rpy="0 0 0" xyz="0 0 0.0584"/>
    <axis xyz="0 -1 0"/>
    <limit effort="20" lower="0.0" upper="0.04" velocity="0.2"/>
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

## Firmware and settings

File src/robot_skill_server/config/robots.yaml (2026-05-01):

# Multi-robot configuration — single source of truth for all robots in the system.
#
# To add a robot: add a new entry under `robots:`.
# To remove a robot: delete or comment out its entry.
#
# `local: true`  — skill atoms for this robot are launched on the skill-server PC.
# `local: false` — skill atoms run on the robot's own PC and self-register via DDS.
#                  Use skill_atoms_remote.launch.py on the remote PC.
#
# `robot_namespace` (derived from `namespace` below) prefixes only the skill
# atom's own action server (e.g. /meca500/skill_atoms/move_to_named_config).
# MoveIt2 connections (move_group, joint_states, controllers) use the absolute
# paths in `arm_controller_action` and are NOT affected by the namespace.
#
# Network requirements: all PCs must share the same ROS_DOMAIN_ID and have
# ROS_LOCALHOST_ONLY=0, ROS_AUTOMATIC_DISCOVERY_RANGE=SUBNET.

robots:
  meca500:
    namespace: "/meca500"
    planning_group: "meca500_arm"
    velocity_scaling: 0.1
    arm_controller_action: "/joint_trajectory_controller/follow_joint_trajectory"
    allowed_named_configs: ["home"]
    has_gripper: true
    local: true
    # Use "arm_controller" / "gripper_controller" (not the literal controller node
     # names) — check_system_ready_skill.cpp dispatches on these system labels and
     # looks up the actual action-server path via the arm_controller_action /
     # gripper_controller_action params set from robots.yaml (see launch_helpers.py).
    check_systems: ["move_group", "joint_states", "arm_controller", "gripper_controller"]
    workspace:
      min_x: -0.6
      max_x: 0.6
      min_y: -0.6
      max_y: 0.6
      min_z: -0.05
      max_z: 0.7

  # Lab-sim "robot" — launched by sim_lab.launch.py. Same hardware shape as
  # meca500 (same SRDF planning group, same controllers when running against
  # mock_components/GenericSystem) but with NO namespace, so atoms register
  # under bare `/skill_atoms/<name>` paths. That way every preset BT in the
  # repo (full_demo, human_interaction_demo, pick_and_place, seed_*, etc.)
  # works in lab-sim without per-tree `server_name=` overrides.
  #
  # Real-hardware deployments still use the namespaced `meca500` entry above
  # so multi-robot setups stay unambiguous.
  lab_sim:
    namespace: ""
    planning_group: "meca500_arm"
    velocity_scaling: 0.1
    arm_controller_action: "/joint_trajectory_controller/follow_joint_trajectory"
    allowed_named_configs: ["home"]
    has_gripper: true
    local: true
    # No real camera on the dev box — DetectObject and CapturePointCloud
    # synthesise positive results so trees that depend on perception
    # (full_demo, pick_and_place, seed_collection) round-trip end-to-end
    # in lab-sim without a real camera or detection model.
    simulate_perception: true
    check_systems: ["move_group", "joint_states", "arm_controller", "gripper_controller"]
    workspace:
      min_x: -0.6
      max_x: 0.6
      min_y: -0.6
      max_y: 0.6
      min_z: -0.05
      max_z: 0.7

  # Franka FR3 + Franka Hand. The FR3's MoveIt2 runs on its own PC alongside
  # the franka_gripper_node; skill atoms are launched on that PC via
  # `pixi run fr3-real-up` (or per-component via `fr3-atoms-run`).
  #
  # `check_systems` deliberately omits `gripper_controller` because the
  # Franka Hand is NOT a ros2_control controller — it's a separate
  # franka_gripper action server. Gripper readiness is exercised
  # implicitly by the FrankaGripperControl skill (mode=HOMING) at the
  # start of each tree.
  fr3:
    namespace: "/fr3"
    planning_group: "fr3_arm"
    velocity_scaling: 0.3
    arm_controller_action: "/fr3_arm_controller/follow_joint_trajectory"
    allowed_named_configs: ["ready", "extended"]
    has_gripper: true
    local: false
    check_systems: ["move_group", "joint_states", "arm_controller"]
    workspace:
      min_x: -0.85
      max_x: 0.85
      min_y: -0.85
      max_y: 0.85
      min_z: 0.0
      max_z: 1.2

  # FR3 lab-sim peer of the meca500 lab_sim entry. Same SRDF planning group
  # but at root namespace so test BTs (test_fr3_sim.xml) need no overrides.
  fr3_lab_sim:
    namespace: ""
    planning_group: "fr3_arm"
    velocity_scaling: 0.3
    arm_controller_action: "/fr3_arm_controller/follow_joint_trajectory"
    allowed_named_configs: ["ready", "extended"]
    has_gripper: true
    local: true
    # franka_gripper_node is NOT launched in sim (it can't talk to libfranka
    # without a real robot). The franka_gripper_skill atom short-circuits via
    # simulate_grasp:=true so trees still resolve FrankaGripperControl goals.
    simulate_perception: true
    check_systems: ["move_group", "joint_states", "arm_controller"]
    workspace:
      min_x: -0.85
      max_x: 0.85
      min_y: -0.85
      max_y: 0.85
      min_z: 0.0
      max_z: 1.2

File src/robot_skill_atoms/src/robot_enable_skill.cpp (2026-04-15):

#include "robot_skill_atoms/skill_base.hpp"

#include <memory>
#include <string>
#include <vector>

#include "robot_skills_msgs/action/robot_enable.hpp"
#include "robot_skills_msgs/msg/skill_description.hpp"

#include "controller_manager_msgs/srv/switch_controller.hpp"
#include "controller_manager_msgs/srv/list_controllers.hpp"

namespace robot_skill_atoms
{

class RobotEnableSkill
  : public SkillBase<robot_skills_msgs::action::RobotEnable>
{
public:
  using RobotEnable = robot_skills_msgs::action::RobotEnable;
  using Base = SkillBase<RobotEnable>;
  using typename Base::GoalHandle;
  using typename Base::Goal;
  using typename Base::Result;
  using typename Base::Feedback;

  explicit RobotEnableSkill(
    const rclcpp::NodeOptions & options = rclcpp::NodeOptions())
  : SkillBase<RobotEnable>(
      "robot_enable_skill",
      "/skill_atoms/robot_enable",
      options)
  {
    this->declare_parameter("controllers_to_activate",
      std::vector<std::string>{"joint_trajectory_controller"});
    this->declare_parameter("switch_controller_service",
      "/controller_manager/switch_controller");
    this->declare_parameter("list_controllers_service",
      "/controller_manager/list_controllers");
  }

  robot_skills_msgs::msg::SkillDescription getDescription() override
  {
    robot_skills_msgs::msg::SkillDescription desc;
    desc.name = "robot_enable";
    desc.display_name = "Robot Enable/Disable";
    desc.description =
      "Enable (servo on) or disable (servo off) the robot by activating or "
      "deactivating ros2_control controllers.";
    desc.version = "1.0.0";
    desc.category = "system";
    desc.tags = {"system", "enable", "disable", "controller"};

    desc.preconditions = {};
    desc.postconditions = {"robot_enabled_state_set"};

    desc.parameters_schema = R"json({
      "type": "object",
      "required": ["enable"],
      "properties": {
        "enable": {
          "type": "boolean",
          "description": "true=enable (servo on), false=disable (servo off)"
        }
      }
    })json";

    desc.action_type = "robot_skills_msgs/action/RobotEnable";
    desc.is_compound = false;
    return desc;
  }

  std::shared_ptr<Result> executeGoal(
    const std::shared_ptr<GoalHandle> goal_handle) override
  {
    auto result = std::make_shared<RobotEnable::Result>();
    const auto & goal = goal_handle->get_goal();

    RCLCPP_INFO(this->get_logger(),
      "Executing RobotEnable: enable=%s", goal->enable ? "true" : "false");

    auto feedback = std::make_shared<RobotEnable::Feedback>();

    try {
      const auto controllers = this->get_parameter("controllers_to_activate")
        .as_string_array();
      const auto switch_srv = this->get_parameter("switch_controller_service")
        .as_string();

      auto client = this->create_client<controller_manager_msgs::srv::SwitchController>(
        switch_srv);

      if (!client->wait_for_service(std::chrono::seconds(5))) {
        result->success = false;
        result->message = "SwitchController service not available at " + switch_srv;
        return result;
      }

      auto request = std::make_shared<controller_manager_msgs::srv::SwitchController::Request>();

      if (goal->enable) {
        request->activate_controllers = controllers;
        request->strictness =
          controller_manager_msgs::srv::SwitchController::Request::BEST_EFFORT;
        feedback->status_message = "Activating controllers...";
      } else {
        request->deactivate_controllers = controllers;
        request->strictness =
          controller_manager_msgs::srv::SwitchController::Request::BEST_EFFORT;
        feedback->status_message = "Deactivating controllers...";
      }
      goal_handle->publish_feedback(feedback);

      auto future = client->async_send_request(request);
      if (rclcpp::spin_until_future_complete(
            this->get_node_base_interface(), future,
            std::chrono::seconds(10)) != rclcpp::FutureReturnCode::SUCCESS)
      {
        result->success = false;
        result->message = "SwitchController service call timed out";
        return result;
      }

      const auto response = future.get();
      result->is_enabled = goal->enable;

      if (response->ok) {
        result->success = true;
        result->message = goal->enable
          ? "Robot enabled (controllers activated)"
          : "Robot disabled (controllers deactivated)";
      } else {
        result->success = false;
        result->message = "SwitchController returned failure";
      }

      RCLCPP_INFO(this->get_logger(), "%s", result->message.c_str());

    } catch (const std::exception & e) {
      result->success = false;
      result->message = "Exception: " + std::string(e.what());
      RCLCPP_ERROR(this->get_logger(), "%s", result->message.c_str());
    }

    return result;
  }
};

}  // namespace robot_skill_atoms

#include "rclcpp_components/register_node_macro.hpp"
RCLCPP_COMPONENTS_REGISTER_NODE(robot_skill_atoms::RobotEnableSkill)

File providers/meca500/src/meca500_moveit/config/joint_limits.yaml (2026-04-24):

# See the robot user manual table 7

# Author: Garrison Johnston 12/2025

# For beginners, we downscale velocity and acceleration limits.
# You can always specify higher scaling factors (<= 1.0) in your motion requests.  # Increase the values below to 1.0 to always move at maximum speed.
default_velocity_scaling_factor: 0.1
default_acceleration_scaling_factor: 0.1

joint_limits:
  joint1:
    has_velocity_limits: true
    max_velocity: 2.61799 # 150 deg/s
    has_acceleration_limits: true
    max_acceleration: 5.0
  joint2:
    has_velocity_limits: true
    max_velocity: 2.61799 # 150 deg/s 
    has_acceleration_limits: true
    max_acceleration: 5.0
  joint3:
    has_velocity_limits: true
    max_velocity: 3.14159 # 180 deg/s
    has_acceleration_limits: true
    max_acceleration: 5.0
  joint4:
    has_velocity_limits: true
    max_velocity: 5.23599 # 300 deg/s
    has_acceleration_limits: true
    max_acceleration: 5.0
  joint5:
    has_velocity_limits: true
    max_velocity: 5.23599 # 300 deg/s
    has_acceleration_limits: true
    max_acceleration: 5.0
  joint6:
    has_velocity_limits: true
    max_velocity: 8.72665 # 500 deg/s
    has_acceleration_limits: true
    max_acceleration: 5.0
  meca_gripper_finger1_joint:
    has_velocity_limits: true
    max_velocity: 0.05  # ~50 mm/s
    has_acceleration_limits: true
    max_acceleration: 0.5

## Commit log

2026-03-06 init commit
    [joint_limits.yaml, ros2_controllers.yaml, sim_robot.urdf.xacro]
2026-03-19 Fix bugs, add tests, CI, health monitoring, and code quality
    Phase 1 — immediate fixes:
    - CMakeLists: fix empty target_link_libraries(skills_node) → link rclcpp_components
    - bt_executor: use os.setsid process group so kill reaches child processes
    - bt_executor: subscribe to /skill_server/bt_runner_status/{task_id} for live
    current_node feedback (was stuck at "initializing")
    - move_to_named_config: remove unused #include <thread>
    - move_to_cartesian_pose: remove unused tf_buffer_ / tf_listener_ members and
    their dead tf2_ros includes
    - detect_object_skill: remove dead tf private members
    Phase 2 — code quality:
    - task_composer: replace always-passing ScriptCondition placeholder stri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
2026-03-30 Working in lite with viewer
    [panda.urdf]
2026-03-30 gripper show correctly
2026-04-15 homing successful
    [6well-insert.stl, meca_500_r3_base.stl, meca_500_r3_j1.stl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]
2026-04-15 fixed bt tree and sim
    [meca_500_r3_base.stl, meca_500_r3_j1.stl, meca_500_r3_j2.stl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]
2026-04-17 seed moving
    [6well-insert.stl]
2026-04-24 Squashed 'providers/meca500/' content from commit 7ad6aab
    git-subtree-dir: providers/meca500
    git-subtree-split: 7ad6aabfc6c94ba30a4619e5285c40b0c16bb0f6
    [camera_calibration.yaml, controllers.yaml, joint_limits.yaml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]
2026-04-24 sim working
    [meca500.ros2_control.xacro, meca500.urdf.xacro, robots.yaml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]
2026-04-25 ui stepping
    [robots.yaml, test_meca500_sim.xml]
2026-04-25 mecatable table tidy up
    [mecatable-simple.stl, mecatable.stl, mecatable_optimized.stl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]
2026-04-26 panda_sim provider tree
    [joint_limits.yaml, panda.urdf, ros2_controllers.yaml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]
2026-04-26 header-pinned cancel button
2026-04-26 fake perception + grasp success in sim mode
    [robots.yaml]
2026-04-26 auto-derive output ports from action result slots
2026-04-27 pausing and campaigns
    [test_imaging_sim.xml]
2026-04-30 imagingin station
    [meca500.urdf.xacro, meca500.xacro, microscope-camera.stl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]
2026-05-01 franka integration
    [ee_with_one_link.xacro, fr3.srdf.xacro, fr3.urdf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]
